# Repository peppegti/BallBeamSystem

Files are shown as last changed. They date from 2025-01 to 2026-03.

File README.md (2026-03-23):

# Ball and Beam System Repository  

The **Ball and Beam system** is a classic educational tool in control systems engineering. It is widely used to demonstrate the challenges of stabilizing an unstable, nonlinear dynamic system. The setup consists of a beam pivoting around a hinge, allowing a ball to roll along its length. The control objective is to regulate the ball's position on the beam by adjusting its tilt angle.  

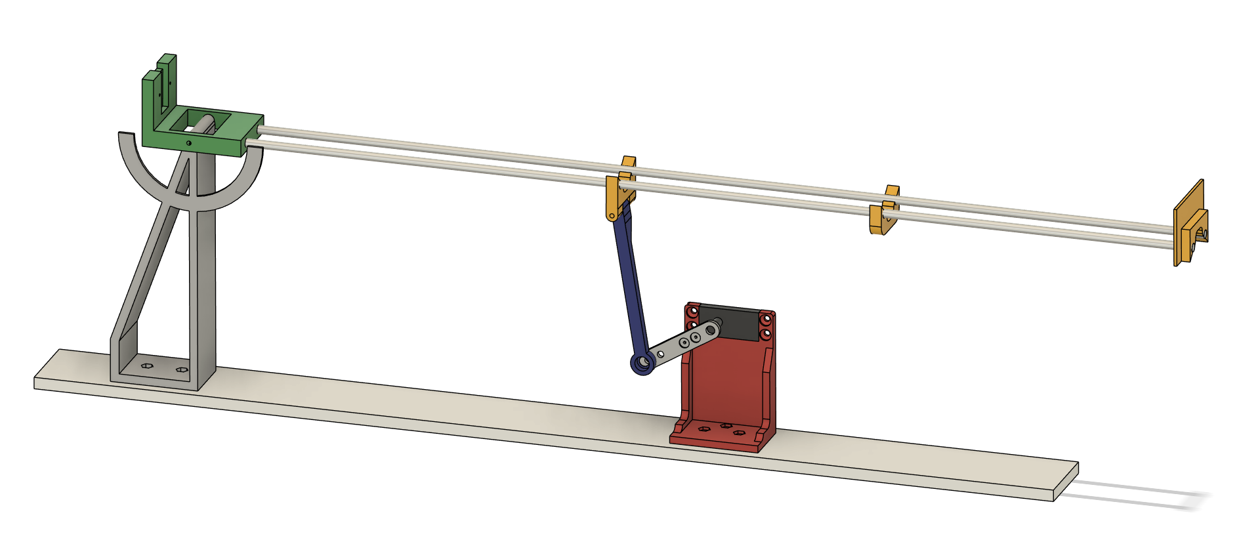
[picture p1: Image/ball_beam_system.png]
Ball and Beam System Ball and Beam System Setup


This system is inherently unstable—any slight tilt causes the ball to roll away from its desired position, accelerated by gravity. The further the beam tilts, the faster the ball moves, making stabilization increasingly difficult. To counteract this instability, a feedback control strategy is employed. In this project, a **Proportional-Integral-Derivative (PID) controller** is implemented to maintain the ball's position by continuously adjusting the beam angle based on real-time feedback from a distance sensor.  

---

## Repository Structure  

The repository is organized into the following directories:  

### 1. **Arduino/**  
This folder contains the Arduino code that is responsible for implementing the PID controller. The code reads real-time feedback from the Time-of-Flight (ToF) sensor and adjusts the angle of the beam via a servo motor to stabilize the ball.  

### 2. **Matlab/**  
This folder includes a MATLAB script for plotting the system's **Bode diagram**. The script helps analyze the system's frequency response and evaluate the stability and performance of the PID controller.  

### 3. **STL/**  
This folder contains all the 3D printable **STL files** required to build the physical components of the Ball and Beam system, including the beam, supports, and sensor mounts.
Each file in the STL folder requires one piece to be printed, except for the file clip, which requires two pieces.
 
---

## Components Required  

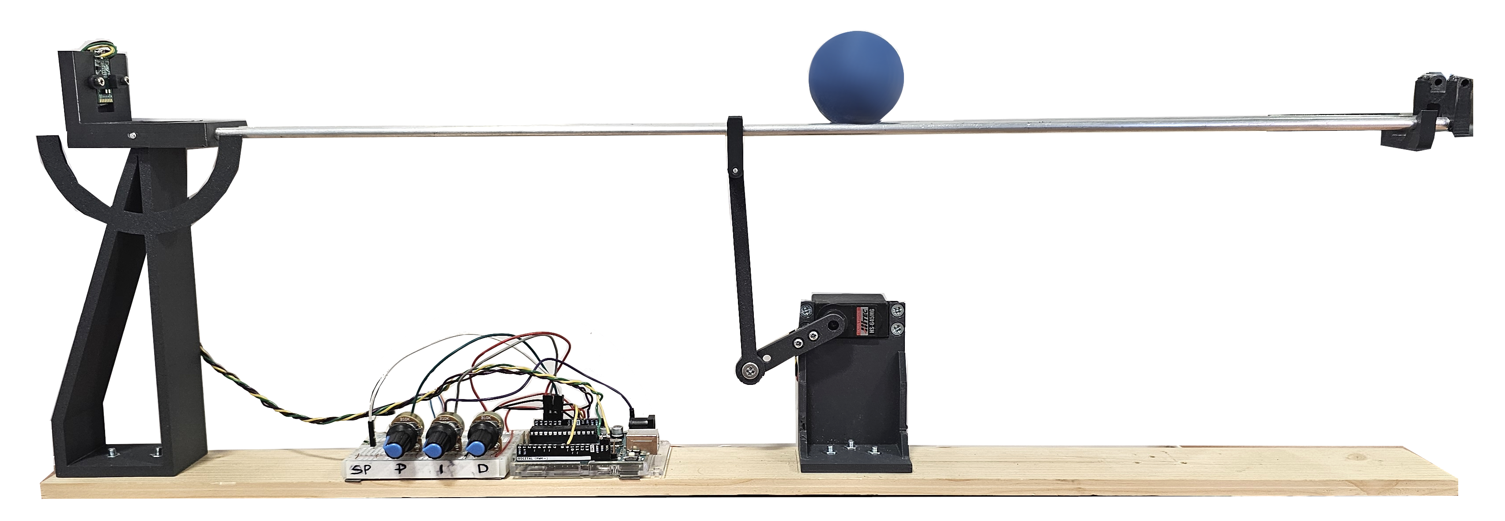
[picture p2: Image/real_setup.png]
Ball and Beam Real System Ball and Beam System Real Setup


| Qty | Component | Description | Image |
|-----|---|---|---|
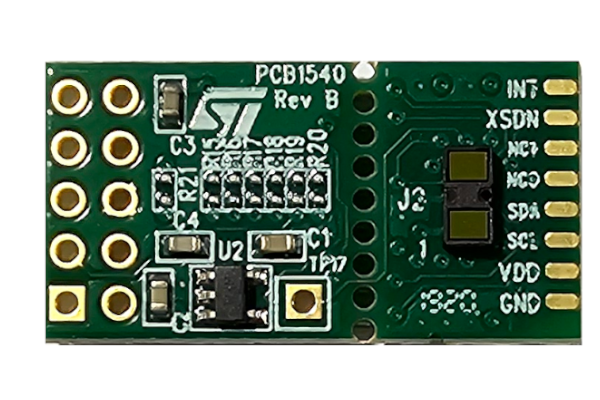
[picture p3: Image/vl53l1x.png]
|  1  | **VL530L1** | Distance sensor with breakout board |   |
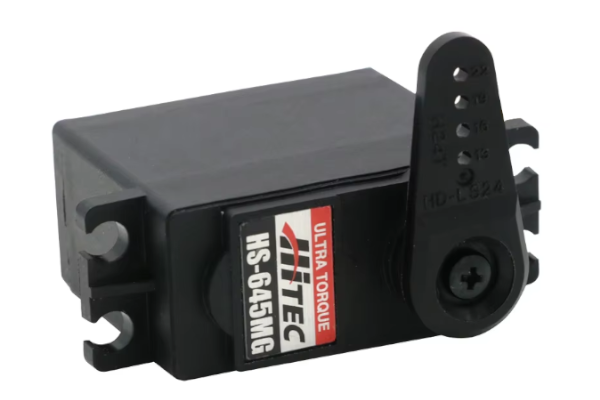
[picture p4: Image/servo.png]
|  1  | **Servo Motor** | Hitec HS-645MG is used to control the tilt of the beam |   |
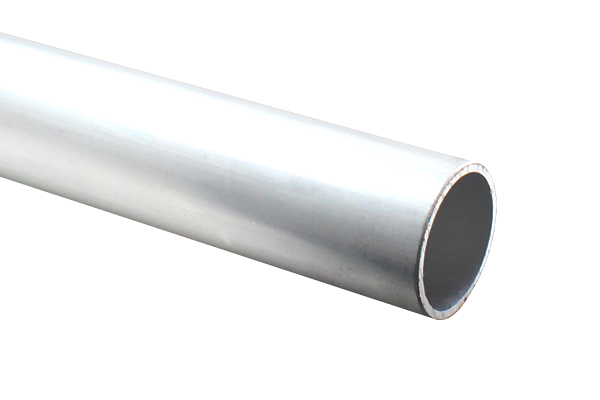
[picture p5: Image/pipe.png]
|  2  | **Aluminum bars** | 5 mm diameter, 60 cm for the beam |   |
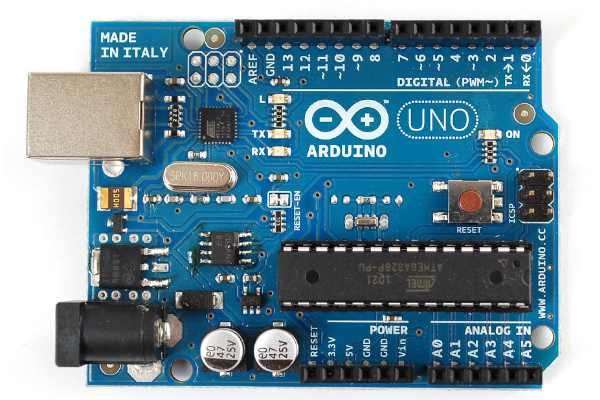
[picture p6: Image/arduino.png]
|  1  | **Arduino Uno** | Microcontroller for PID implementation |   |
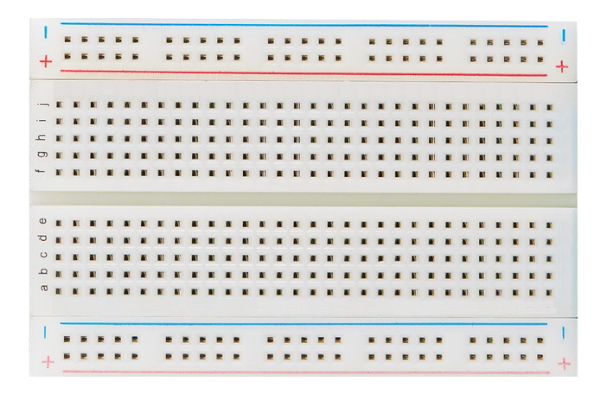
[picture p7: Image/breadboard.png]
|  1  | **Breadboard** | For connecting the circuit components |   |
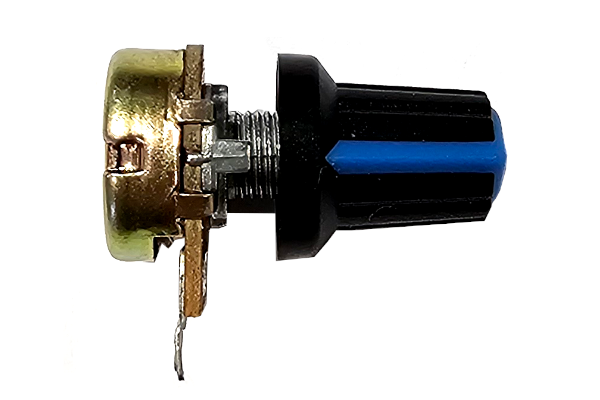
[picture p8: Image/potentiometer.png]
|  4  | **Potentiometer** | For manual tuning of PID parameters |   | 
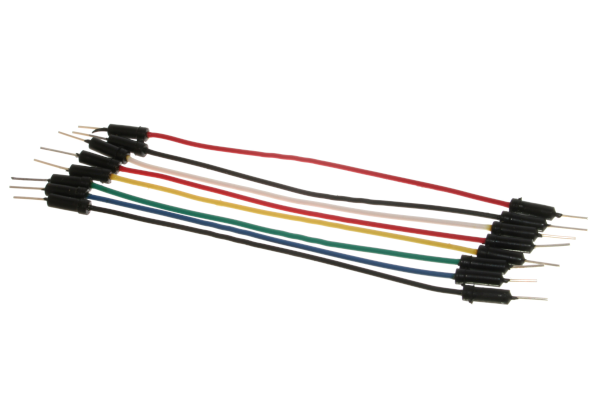
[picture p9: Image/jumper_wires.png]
| N/A | **Jumper Wires** | For connecting components |   |
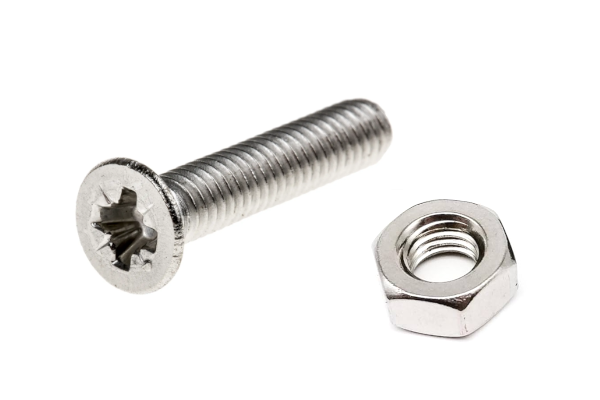
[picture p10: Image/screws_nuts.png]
| 10  | **M4 Screws and Nuts**  | For assembling the system |   |
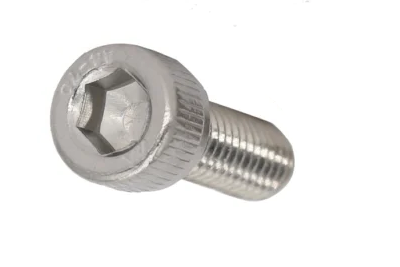
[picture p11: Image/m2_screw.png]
|  2  | **M2 Screws** | To fix the ToF sensor through the two clips. |   |
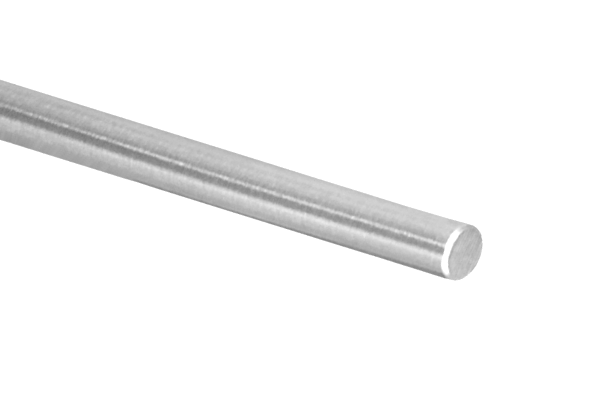
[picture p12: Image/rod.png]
|  2  | **Aluminum Rod** | 3 mm diameter, 5 cm length, solid cylindrical rod used as a fixing pin |   |
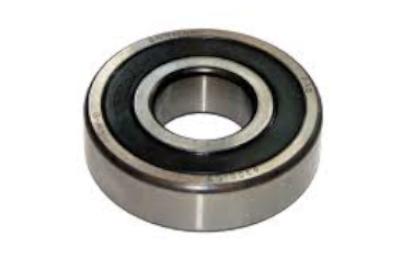
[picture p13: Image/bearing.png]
|  1  | **Bearing** | Inner diameter 4 mm, outer diameter 10 mm, thickness 4 mm. |   |

----

## Tools Required  

To assemble the Ball and Beam system, you will need the following tools:  

- **3D Printer**: Printing the components from the STL files in the `STL/` folder.  
- **Screwdrivers**: For assembling and securing the components.  
- **Drill and Drill Bits**: These are used to create/clean any holes required for mounting.  
- **Hacksaw**: This cuts the aluminum pipe and rod to the desired length.  
- **Wire Cutter (Tronchesina)**: For trimming jumper wires or cables.  
- **Pliers**: For holding components and securing nuts during assembly.

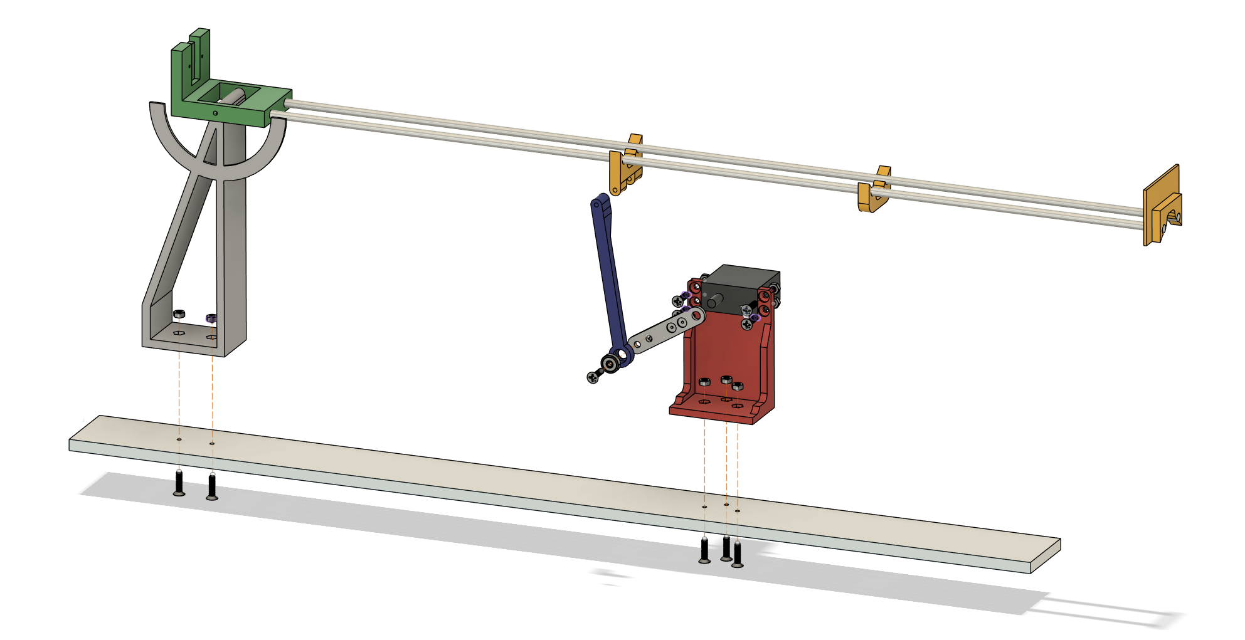
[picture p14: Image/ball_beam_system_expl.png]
How to assemble the prototype Assembly example


---

## How to Use This Repository  

1. **Build the Physical System**  
   - Use the STL files in the `STL/` folder to 3D print the necessary components.  
   - Assemble the system following the provided design and attach all components using the screws and nuts.

2. **Upload the Arduino Code**  
   - Connect the Time-of-Flight sensor, potentiomers, and servo motor to the Arduino.  
   - Upload the code from the `Arduino/` folder to the Arduino board.
   - The following libraries are required to run the system. They can be found at the links below:
      - [VL53L1X](https://github.com/peppegti/Adafruit_VL53L1X)
      - [Arduino-PID_v1](https://github.com/peppegti/Arduino-PID_v1)

3. **Analyze the System**  
   - Use the MATLAB script in the `Matlab/` folder to generate the Bode diagram and assess the system’s performance.  

---

## Contributing  

If you have suggestions for improvements or encounter any issues, feel free to submit a pull request or open an issue in this repository.  

---

## License  

This repository is licensed under the MIT License. By using, modifying, or distributing the code and resources in this repository, you agree to the terms and conditions outlined in the license file.

Please cite this work as:  

<div style="background-color: #f9f9f9; padding: 10px; border: 1px solid #ddd; border-radius: 5px;">
   <pre>
       @article{sutera2026design,
       title={Design and Implementation of a Ball and Beam Control System Using a PID Controller},
       author={Sutera, Giuseppe and Guastella, Dario Calogero and Cancelliere, Francesco and Muscato, Giovanni},
       journal={IEEE Transactions on Education},
       year={2026},
       publisher={IEEE}
         url={https://ieeexplore.ieee.org/abstract/document/11361191/}
       }
   </pre>
</div>

@author Giuseppe Sutera giuseppe.sutera@unict.it 

Copyright (C) 2024

---

`Enjoy it while you can 🍾🍾➕ `

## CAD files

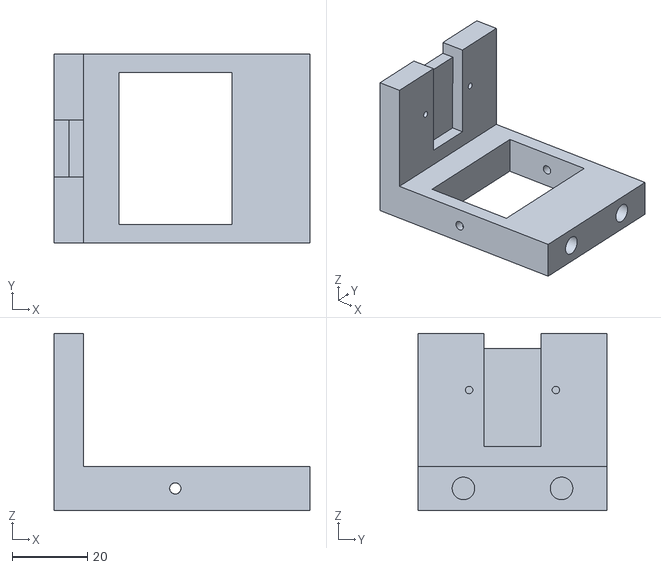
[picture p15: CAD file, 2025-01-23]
STL/main_joint.stl
67.8 x 50.0 x 46.9

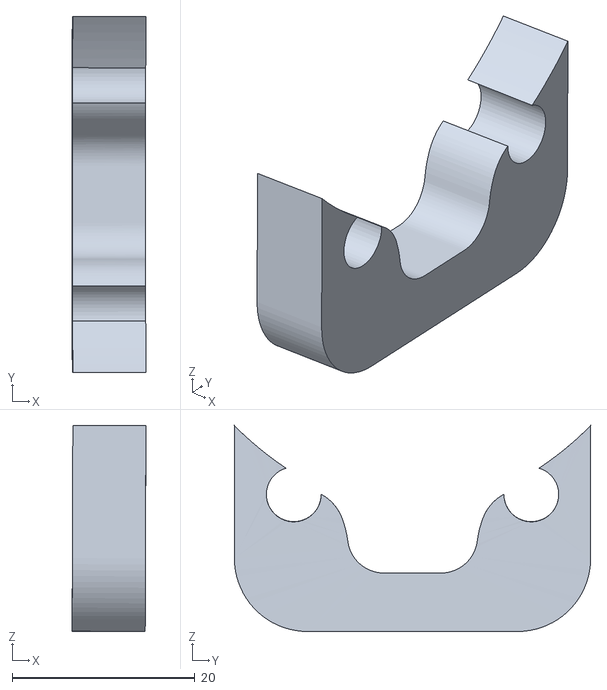
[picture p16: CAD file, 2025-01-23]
STL/fork_support.stl
8.08 x 39.0 x 22.5

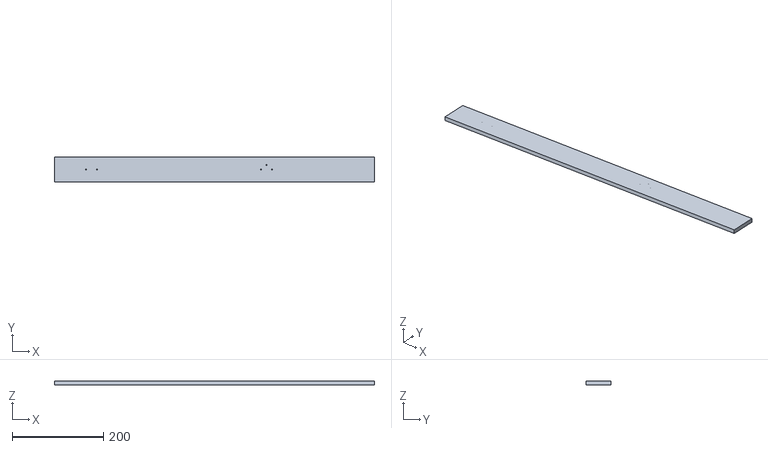
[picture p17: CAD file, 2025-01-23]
STL/base_link.stl
700.0 x 55.0 x 8.00

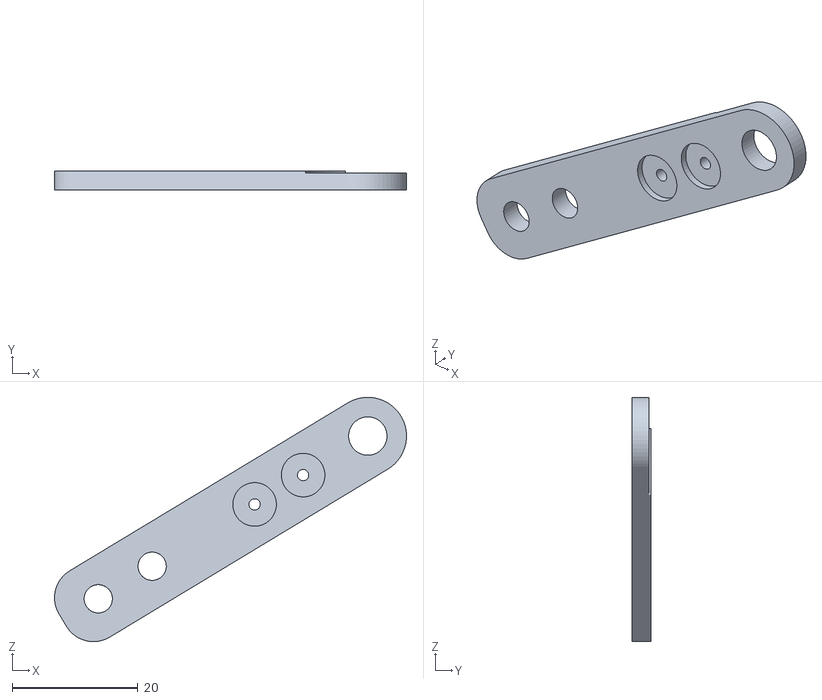
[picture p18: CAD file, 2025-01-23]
STL/servo_link.stl
55.9 x 3.00 x 38.8

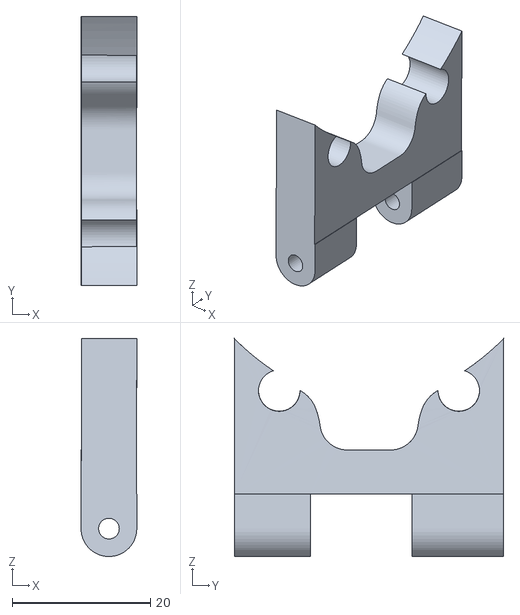
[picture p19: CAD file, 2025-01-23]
STL/fork_link.stl
8.10 x 39.0 x 31.6

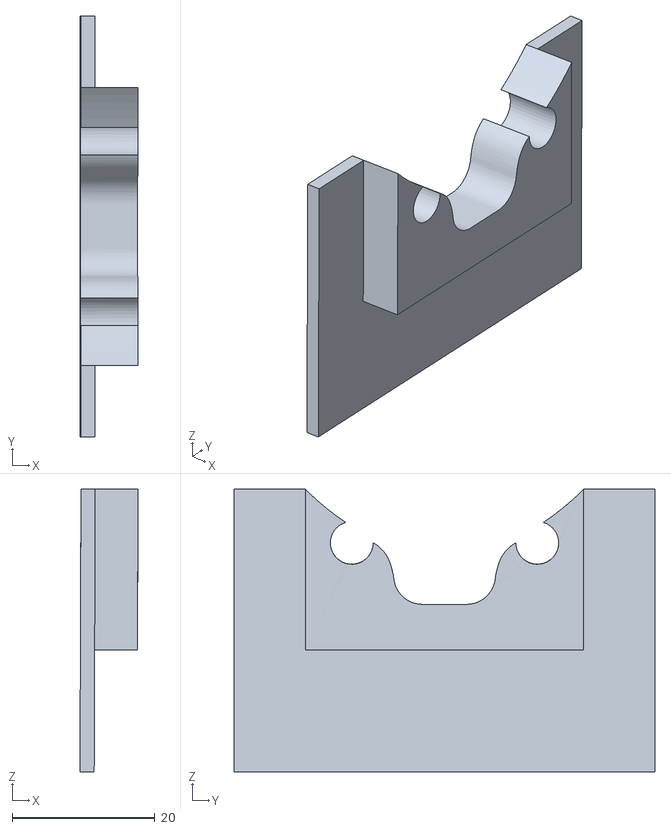
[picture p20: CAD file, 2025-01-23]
STL/fork_stop.stl
8.14 x 59.0 x 39.6

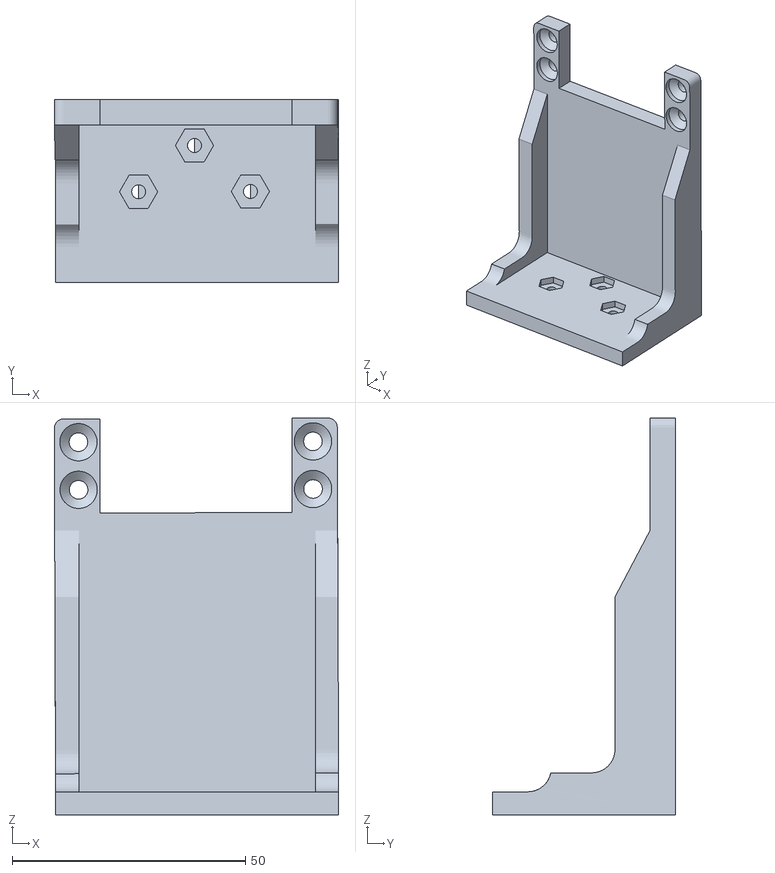
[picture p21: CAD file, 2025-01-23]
STL/servo_support.stl
60.9 x 39.3 x 85.0

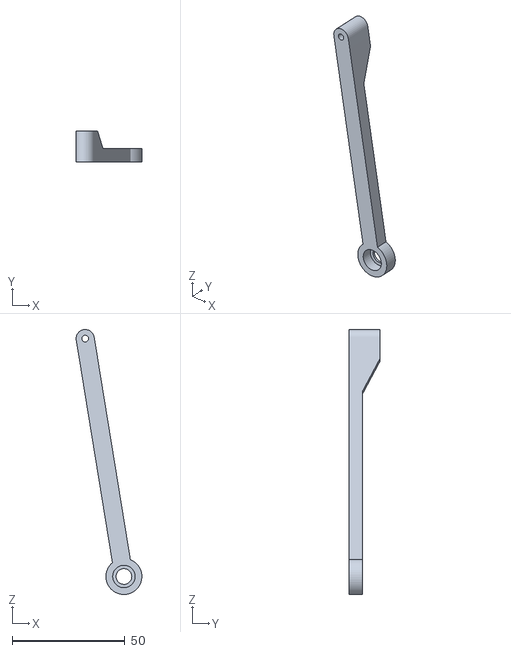
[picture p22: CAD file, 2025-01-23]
STL/link_servo2fork.stl
29.2 x 13.7 x 117.7

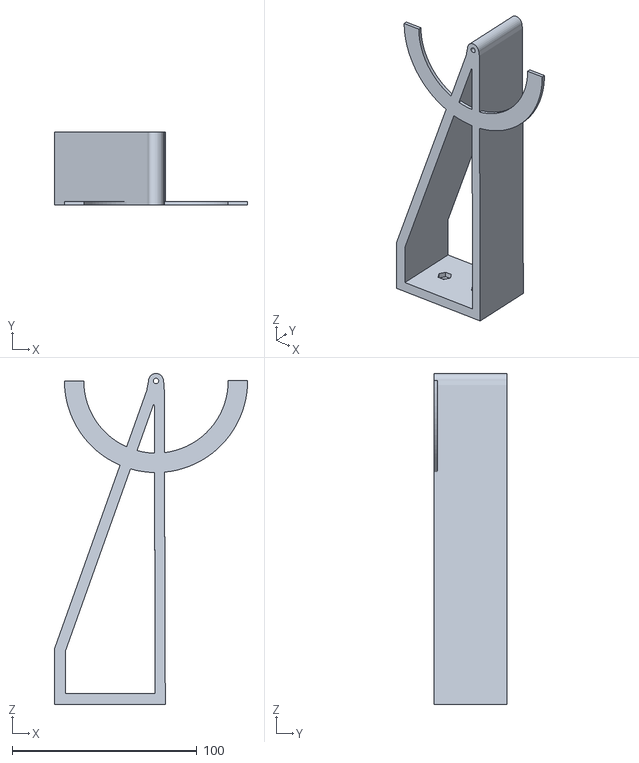
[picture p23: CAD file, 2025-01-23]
STL/tower.stl
104.5 x 39.6 x 179.0

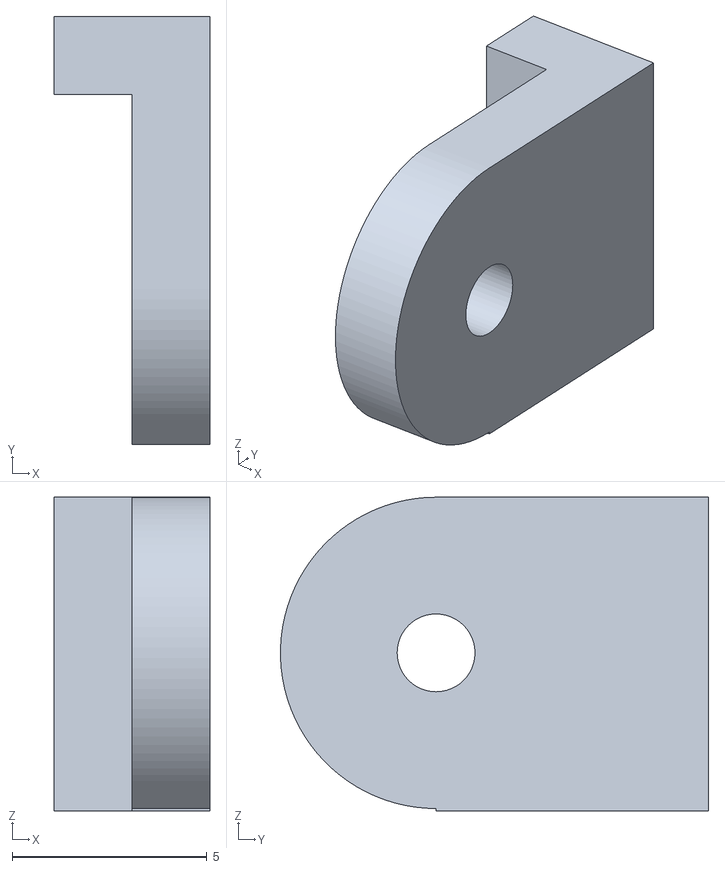
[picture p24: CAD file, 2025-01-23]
STL/clip.stl
4.00 x 11.0 x 8.06

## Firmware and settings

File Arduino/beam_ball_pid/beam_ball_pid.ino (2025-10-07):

#include <Servo.h>
#include <PID_v1.h>
#include "Adafruit_VL53L1X.h"
#include <Adafruit_NeoPixel.h>

// Definizione pin e oggetti
#define IRQ_PIN 2
#define XSHUT_PIN 3
#define LED_PIN 6
#define NUMPIXELS 1
#define PIN_START 7

Adafruit_VL53L1X vl53 = Adafruit_VL53L1X(XSHUT_PIN, IRQ_PIN);
Adafruit_NeoPixel pixels(NUMPIXELS, LED_PIN, NEO_GRB + NEO_KHZ800);

const int servoPin = 9;
const int setposition = A0;  // Collega il potenziometro al pin analogico A0
const int set_p = A1;  // Collega il potenziometro al pin analogico A1
const int set_i = A2;  // Collega il potenziometro al pin analogico A2
const int set_d = A3;  // Collega il potenziometro al pin analogico A3

const float tolerance = 2.0;  // Tolleranza di 1 cm

// tuning PID here
float Kp = 0.5; // Proportional Gain
float Ki = 0.0; // Integral Gain
float Kd = 0.2; // Derivative Gain
double Setpoint, Input, Output, ServoOutput;

PID myPID(&Input, &Output, &Setpoint, Kp, Ki, Kd, DIRECT); // Initialize PID object, which is in the class PID.
Servo myServo; // Initialize Servo.
uint32_t last_read = 0;

void setup() {
  Serial.begin(115200);
  while (!Serial) delay(10);
  pinMode(PIN_START, INPUT);

  Serial.println(F("Adafruit VL53L1X sensor demo"));

  Wire.begin();
  if (!vl53.begin(0x29, &Wire)) {
    Serial.print(F("Error on init of VL sensor: "));
    Serial.println(vl53.vl_status);
    while (1) delay(10);
  }
  Serial.println(F("VL53L1X sensor OK!"));

  if (!vl53.startRanging()) {
    Serial.print(F("Couldn't start ranging: "));
    Serial.println(vl53.vl_status);
    while (1) delay(10);
  }
  Serial.println(F("Ranging started"));

  vl53.setTimingBudget(50);
  Serial.print(F("Timing budget (ms): "));
  Serial.println(vl53.getTimingBudget());

  vl53.VL53L1X_SetROI(4, 4);


  myServo.attach(servoPin); // Attach Servo

  pixels.begin(); // Initialize NeoPixel strip
  pixels.show();  // Initialize all pixels to 'off'

  Input = readPosition(); // Sets the initial input to the PID algorithm
  myPID.SetMode(AUTOMATIC); // Set PID object myPID to AUTOMATIC
  myPID.SetOutputLimits(-20, 20); // Set Output limits
  myPID.SetSampleTime(20);
}

void loop() {
    last_read = millis();
    int potValue = analogRead(setposition); // Legge il valore dal potenziometro
    Setpoint = map(potValue, 0, 1023, 0, 66); // Mappa il valore letto da 0 a 1023 a 0 a 66
    Kp = map(analogRead(set_p), 0, 1023, 0, 1000) * 0.01;
    Ki = map(analogRead(set_i), 0, 1023, 0, 500) * 0.0001;
    Kd = map(analogRead(set_d), 0, 1023, 0, 500) * 0.01;

    myPID.SetTunings(Kp, Ki, Kd);
    Input = readPosition();
    myPID.Compute(); // Computes Output in range of -60 to 60 degrees
    ServoOutput = 82 - Output; // 82 degrees is the horizontal, can change depending on the current angle of the motor
    myServo.write(ServoOutput); // Writes value of Output to servo

    // Controlla la distanza e accende il LED corrispondente
    if (abs(Input - Setpoint) <= tolerance) {
      pixels.setPixelColor(0, pixels.Color(0, 0, 255)); // Blu
    } else if (Input > Setpoint + tolerance) {
      pixels.setPixelColor(0, pixels.Color(0, 255, 0)); // Verde
    } else {
      pixels.setPixelColor(0, pixels.Color(255, 0, 0)); // Rosso
    }
    pixels.show(); // Aggiorna il LED

    // Stampa i valori su Serial per il plotter
    Serial.print("Timestamp:");
    Serial.print(millis());
    Serial.print(",");
    Serial.print("Distance:");
    Serial.print(Input);
    Serial.print(",");
    Serial.print("output:");
    Serial.print(Output);
    Serial.print(",");
    Serial.print("Kp:");
    Serial.print(Kp);
    Serial.print(",");
    Serial.print("Ki:");
    Serial.print(Ki, 4);
    Serial.print(",");
    Serial.print("Kd:");
    Serial.print(Kd, 4);
    Serial.print(",");
    Serial.print("Setpoint:");
    Serial.println(Setpoint);

}

float readPosition() {
  int16_t distance = -1;
  while (distance == -1) {
    if (vl53.dataReady()) {
      distance = vl53.distance();
      if (distance == -1) {
        Serial.print(F("Couldn't get distance: "));
        Serial.println(vl53.vl_status);
      } else {
        //Serial.print(F("Raw Distance: "));
        //Serial.println(distance);
      }
      vl53.clearInterrupt();
    }
    //delay(10); // Aggiungere un piccolo ritardo per evitare un loop troppo veloce
  }
  return distance / 10.0; // Convert mm to cm
}
